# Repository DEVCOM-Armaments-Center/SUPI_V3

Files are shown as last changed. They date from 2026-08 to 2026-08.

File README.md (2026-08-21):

# sUPI — Small Universal Payload Interface

**Technical Data Package, Version 3.3**

> **DISTRIBUTION STATEMENT A. APPROVED FOR PUBLIC RELEASE; DISTRIBUTION IS UNLIMITED.**

---

## Overview

sUPI is an interchangeable mechanical and electrical interface for attaching payloads to uncrewed
systems, primarily small UAS.

The interface is two mating halves, each with its own machined hardware and circuit board:

| Half | Mounts to | Board | Role |
| --- | --- | --- | --- |
| **Platform Side** | The vehicle | `100069026-001` | Gates and monitors payload power; switches USB; hosts the interface MCU |
| **Payload Side** | The payload | `100068610-001` | Regulates platform battery down to payload rails; carries the payload ID device |

Power, USB, and GPIO cross the interface on spring contacts, so the halves mate and separate without
a cable or locking connector. The platform side is the intelligent end: a detect mechanism lets it
identify an attached payload and gate the payload signals accordingly.

Start with [`sUPI_Platform_Brief.md`](sUPI_Platform_Brief.md) or
[`sUPI_Payload_Brief.md`](sUPI_Payload_Brief.md) depending on which side you are integrating.

---

## Electrical Interface

### Platform → Platform-Side Board

| Signal | Range |
| --- | --- |
| `VBATT` / `VBATT_RET` | 13 – 25.2 VDC (4S–6S pack) |
| `GPIO` | Typically PWM, ±5 VDC |
| `USB` | 0 – 3.3 VDC |

### Payload-Side Board → Payload

| Signal | Range |
| --- | --- |
| `VBATT` / `VBATT_RET` | 13 – 25.2 VDC, passed through |
| `V1` | Regulated **3.3 or 5 VDC** — set by solder bridge |
| `V2` | Regulated **5, 7.4, or 12 VDC** — set by solder bridge |
| `GPIO` | Typically PWM, ±5 VDC |
| `USB` | 0 – 3.3 VDC |

> **V1 and V2 are hardware-selected.** The rails are set by solder-bridge placement
> at build time. Verify the bridges match the payload before first power-on.

Both boards use solder pads for field wiring: 18–22 AWG for power, 24–30 AWG for signals.

### Board Markings

- **Platform pads:** `VBATT`, `GND`, `GPIO 0`, `GPIO 1`, `+USB−`, `AUX`
- **Platform jumpers:** `DETECT PAYLOAD`, `SELECT`, `FORCE ON`, `LO BATT CUTOFF`
- **Payload pads:** `VBATT`, `GND`, `V1`, `V1 OK`, `V2`, `V2 OK`, `USB DP`, `USB DM`, `GPIO 0`, `GPIO 1`
- **Payload selectors:** `V1SEL` (`3V3` / `5V`), `V2SEL` (`5V` / `7V4` / `12V`)

`FORCE ON` overrides the detect gate — confirm its state before flight.

### Functional Blocks

**Platform side** — 8-layer board.

| Function | Device |
| --- | --- |
| Interface MCU | STM32C011F6 (Arm Cortex-M0+) |
| Payload power switch | MPQ5069, 15 A |
| Current sense | ACS711, ±15 A bidirectional Hall-effect |
| Ideal-diode / reverse-polarity control | NCV68261 driving an N-channel MOSFET |
| Undervoltage supervisor | LTC2965 |
| Logic 3.3 V rail | NCP730 LDO, 150 mA |
| USB routing | TC7USB40MU dual SPDT, MAX20336 DPST |
| Transient protection | 26 V bidirectional TVS on `VBATT`, 3.3 V TVS on signals |

**Payload side** — 4-layer board.

| Function | Device |
| --- | --- |
| V1 / V2 regulation | MAX25254, dual 36 V in / 0.8–14 V out, 8 A synchronous buck |
| Payload ID / detect | DS2431 1-Wire EEPROM, 1 kbit |
| Input protection | NCV68261 + N-channel MOSFET, P-channel blocking FET |
| Logic 3.3 V rail | NCP730 LDO, 150 mA |
| Supply supervisor | MAX821, 2.78 V |
| USB routing | TC7USB40MU dual SPDT, MAX20336 DPST |
| Transient protection | 26 V unidirectional TVS on `VBATT`, 3.3 V TVS on signals |

The DS2431 is what the platform MCU reads to identify an attached payload — a payload built to this
interface inherits an identity device it does not have to implement itself.

### Mating Connection

A **9-contact, 0.100"-pitch right-angle spring-pin interface.** The payload side carries the spring
pins (Mill-Max 829-series); the platform side carries the mating targets (Mill-Max 399-series).

---

## Mechanical Interface

Both halves mount with **M3 × 0.5 mm thread, 8 mm long, black-oxide stainless steel Phillips
flat-head screws.**

| Half | Screws | Controlling drawing |
| --- | --- | --- |
| Platform side | 3X M3 | `19200_13122518` |
| Payload side | 4X M3 | `19200_13122514` |

Two accepted installation methods, either half:

1. **Direct mount** — drill and tap the sUPI hole pattern into the host structure.
2. **Adapter** — fabricate an adapter carrying the sUPI hole pattern on one face and mating to an
   existing interface on the other. Preferred where the host structure cannot be modified.

The payload-side pattern carries a `VEHICLE CG` reference callout — position the interface so the
vehicle center of gravity lands as close to that point as the installation allows.

### Part Tree

Assembly **13122513**, one each of:

| Part No. | Nomenclature | Material | Process / Finish |
| --- | --- | --- | --- |
| `13122514` | V-Mount Base | 6061-T6 per ASTM B209, or polymer powder bed fusion | Bead blast; hard anodize per MIL-A-8625F Type III Class 2, black, sealed |
| `13122515` | Short Button | 6061-T6 per ASTM B209 | Bead blast; hard anodize per MIL-A-8625F Type III Class 2, black, sealed |
| `13122516` | Small Button Cover | PA12 or PA6 | Polymer powder bed fusion (MJF, SLS, or SAF); depowder, media blast, optional black dye |
| `13122517` | Connector Cover | 6061-T6 per ASTM B209, or polymer powder bed fusion | Bead blast; hard anodize per MIL-A-8625F Type III Class 2, black, sealed |
| `13122518` | V-Mount | 6061-T6 per ASTM B209 | Mask/plug threaded holes, then bead blast and hard anodize per MIL-A-8625F Type III Class 2, black, sealed |

Threaded and clearance features:

- `13122514` — 4× M3 clearance, 90° countersunk; 2× M2 × 0.4 tapped
- `13122517` — 2× M2 × 0.4 clearance
- `13122518` — 3× M3 clearance, 90° countersunk; 3× M1.6 × 0.35 tapped, through

Dimensions are in inches; interpret per ANSI/ASME Y14.5M-2009. **The drawings are the authority** —
each detail sheet names a design model required to complete the product definition, and
undimensioned features are taken from that model. Do not machine from the PDFs alone.

---

## Before You Fabricate Boards

The three notes in `sUPI Electrical/` supersede the released BOMs. Read them first.

| Note | Direction |
| --- | --- |
| [`MFR_DNP.md`](sUPI%20Electrical/MFR_DNP.md) | Do not populate platform `U3`, `R1`–`R4`, `C2`, `JP1` — the undervoltage cutoff is still in development and can block power to the payload |
| [`MFR_Rework.md`](sUPI%20Electrical/MFR_Rework.md) | Remove platform `U11` and `U12` and bridge pin 2 to pin 4 on each footprint — a bare do-not-populate leaves the net open and does not implement the workaround |
| [`MFR_Capacitors.md`](sUPI%20Electrical/MFR_Capacitors.md) | Alternate capacitor part numbers for every Murata position on both boards |

With the do-not-populate and rework direction applied, the platform board has **no undervoltage
supervision and no supply supervisor**, and its detect/enable gate is strapped to a permanent
pass-through. If your application depends on brownout protection or supervised power sequencing,
treat that as an open engineering item.

---

## Firmware

`supi_firmware.hex` is the platform MCU image: 20,440 bytes, load address `0x08000000`, targeting the
STM32C011 (Arm Cortex-M0+). Intel HEX format.

---

## Revision History

See [`CHANGELOG.md`](CHANGELOG.md).

v3.3 is a manufacturability and fit release — it removes special tooling from the machining plan and
takes slop out of the mating stack. No electrical interface changes.

**v3.3 hardware is physically marked.** Check the engraved version number before mating
mixed-vintage halves: earlier parts have looser fit, and earlier `13122515` buttons have the taller
profile that was prone to bending.

---

## Package Contents

```
.
├── CHANGELOG.md                     Design change history, v3.1 → v3.3
├── sUPI_Platform_Brief.md           Platform-side integration brief
├── sUPI_Payload_Brief.md            Payload-side integration brief
├── assets/                          Figures for the briefs and changelog
│
├── sUPI Mechanicals/
│   ├── 19200_13122513_v3-3.pdf      Assembly drawing
│   ├── 19200_1312251[4-8]_v3-3.pdf  Detail drawings
│   └── 19200_*_v3-3.stp             Solid models (STEP)
│
├── sUPI Electrical/
│   ├── MFR_DNP.md                   Do-not-populate direction
│   ├── MFR_Rework.md                Platform rework work instructions
│   ├── MFR_Capacitors.md            Capacitor alternate sourcing
│   ├── Platform/
│   │   ├── 100046138_Rev2.pdf       Schematic
│   │   ├── 100069026-001_Rev1_FAB_DWG.pdf
│   │   ├── *.gbr                    Gerbers — 8 copper layers
│   │   ├── *.drl, *-DRL.rpt         Drill files and report
│   │   ├── *.d356                   Bare-board test netlist
│   │   └── *_Rev2__platform_VAL_bom.xlsx
│   └── Payload/
│       ├── 100046137_Rev2.pdf       Schematic
│       ├── 100068610-001_Rev1_FAB_DWG.pdf
│       ├── *.gbr                    Gerbers — 4 copper layers
│       ├── *.drl, *-DRL.rpt         Drill files and report
│       ├── *.d356                   Bare-board test netlist
│       └── *_Rev2_payload_VAL_bom.xlsx
│
└── sUPI Firmware/
    └── supi_firmware.hex            Platform MCU image
```

### Where to Start

| You are | Read, in order |
| --- | --- |
| **Platform integrator** | Platform brief → assembly drawing → platform schematic |
| **Payload integrator** | Payload brief → assembly drawing → payload schematic |
| **Fabricating boards** | `MFR_*.md` notes → BOM → Gerbers, drill, fab drawing |
| **Machining parts** | Detail drawing + its matching STEP model |
| **Bringing up firmware** | Platform schematic, MCU section → `supi_firmware.hex` |

---

## Conventions

- **Mechanical part numbers** are 8-digit design-activity numbers, prefixed in filenames with CAGE
  code `19200` and suffixed with the TDP version (`_v3-3`).
- **Electrical part numbers** are 9-digit with a `-001` dash number and an explicit `_Rev`.
- **Dimensions** are in inches unless otherwise specified; tolerances per ANSI/ASME Y14.5M-2009.
  Untoleranced features carry a 0.005 profile tolerance to datums A-B-C.
- **Mechanical files:** `.pdf` released drawing, `.stp` neutral solid model.
- **Electrical files:** `.pdf` schematic and fab drawing, `.gbr` Gerber layer, `.drl` drill, `.d356`
  bare-board test netlist, `.xlsx` BOM.
- **Packaging and marking** per MIL-STD-2073-1 Method 10 and MIL-STD-130.

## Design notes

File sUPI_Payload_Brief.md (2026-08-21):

# Small Universal Payload Interface (sUPI) — Payload Side Brief

**sUPI v3.3**

> **DISTRIBUTION STATEMENT A. APPROVED FOR PUBLIC RELEASE; DISTRIBUTION IS UNLIMITED.**

---

## Overview

The sUPI interface provides an interchangeable interface to connect payloads to UxS platforms such
as drones. The interface is a subset of the Picatinny Common Lethality Interface Kit (CLIK) Design
Standard. The interface supports a detect mechanism in which the payload signals are controlled by
the platform's interface board. The payload interface board provides power to the payload and
connectivity for USB and GPIOs passed through the physical / electrical interface.

---

## Electrical Interface for Payload

The sUPI payload side electronics board has solder pads for connecting wires to the payload
interfaces. Connections should be made with 18–22 AWG wire for power (`VBATT`, `VBATT_RET`) and
24–30 AWG for signals, as indicated in the wiring diagram (Figure 1).

The payload board will provide regulated power based upon solder bridge placement over the `V1SEL`
and `V2SEL` selections.

| Signal | Range |
| --- | --- |
| `VBATT` | Platform battery, 13 to 25.2 VDC |
| `VBATT_RET` | Battery return |
| `V1` | Regulated power, 3.3 or 5 VDC |
| `V2` | Regulated power, 5, 7.4 or 12 VDC |
| `GPIO` | Typically PWM, ±5 VDC |
| `USB` | 0 to 3.3 VDC |

### Rail Selection

`V1` and `V2` are set by solder bridge at build time; there is no runtime negotiation. Verify the
bridges match the payload's requirements before first power-on.

| Selector | Options |
| --- | --- |
| `V1SEL` | `3V3` or `5V` |
| `V2SEL` | `5V`, `7V4` (7.4 V), or `12V` |

### Solder Pads

The payload board silkscreen labels its wiring pads directly: `VBATT`, `GND`, `V1`, `V1 OK`, `V2`,
`V2 OK`, `USB DP`, `USB DM`, `GPIO 0`, `GPIO 1`.

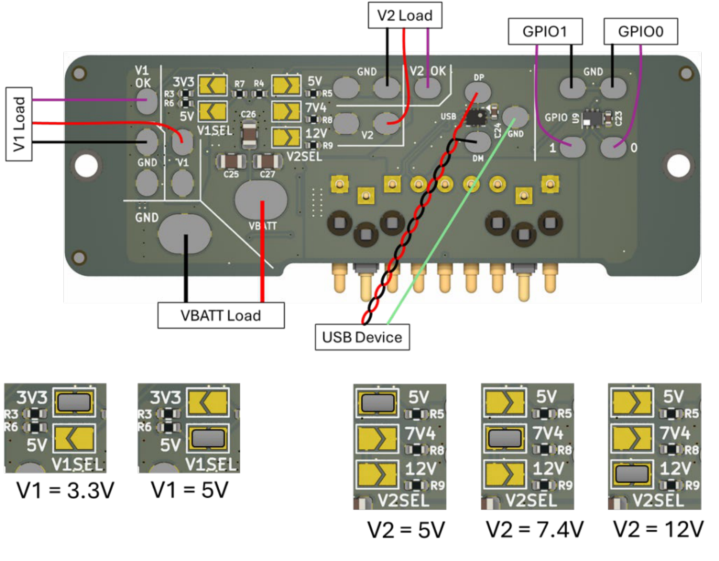
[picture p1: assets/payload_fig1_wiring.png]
Figure 1 — Payload side wiring and rail selection. Board pads at top; V1SEL and V2SEL solder bridge options below.


**Figure 1.** Payload side wiring diagram and rail selection. Lower panels show the valid `V1SEL`
and `V2SEL` solder bridge placements.

---

## Mechanical Interface for Payload

The sUPI Payload Side is intended to be mounted to a payload via **4X M3 × 0.5 mm thread, 8 mm
long, black-oxide stainless steel Phillips flat head screws** (e.g. McMaster PN 91698A304). The
mounting hole pattern is shown in Figure 2.

Existing payloads should be modified in one of the following ways to install a sUPI Payload Side
interface:

- **Drill and tap 4X holes** into the payload as shown in Figure 2, in the desired location for
  mounting the sUPI payload side. For a UAV platform, it is recommended that the vehicle CG align as
  closely as possible with the point indicated in Figure 2.
- **Create a custom adapter** that includes the sUPI Payload Side hole pattern and enables mounting
  to an existing mounting interface on a payload.

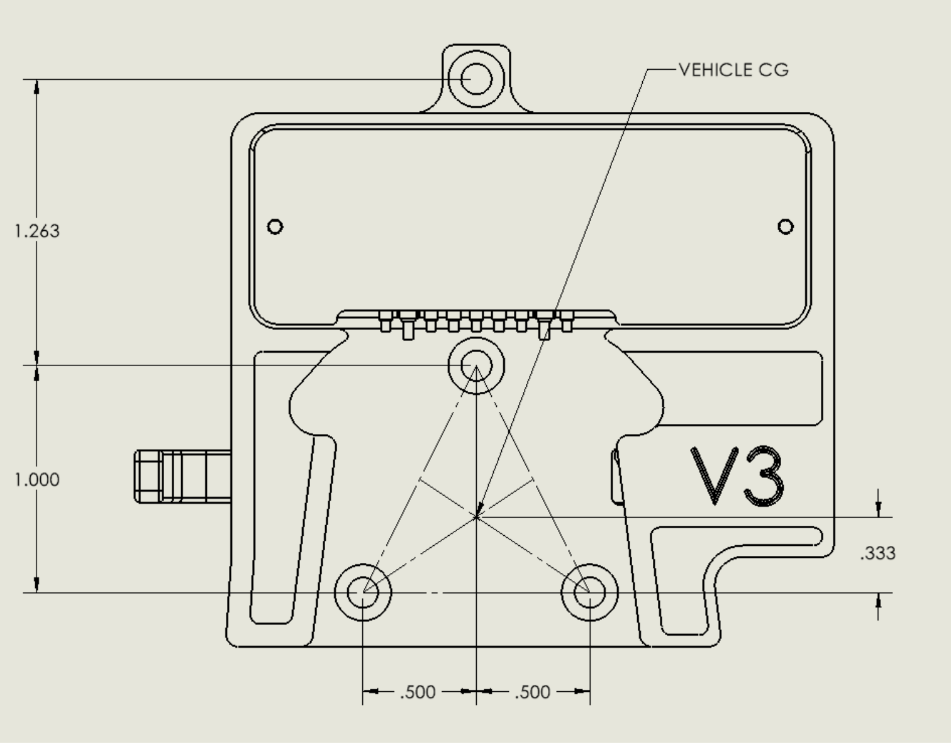
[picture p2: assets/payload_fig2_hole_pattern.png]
Figure 2 — Payload side mounting hole pattern, four M3 holes, with the vehicle CG reference point marked


**Figure 2.** Payload side mounting hole pattern — 4X M3, viewed from the mounting face. Dimensions
in inches. The `VEHICLE CG` callout marks the recommended center-of-gravity reference point. The two
smaller holes are M2 board-mounting features, not host mounting points.

Refer to drawing `19200_13122514` for controlling dimensions and tolerances.

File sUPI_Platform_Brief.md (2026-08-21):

# Small Universal Payload Interface (sUPI) — Platform Side Brief

**sUPI v3.3**

> **DISTRIBUTION STATEMENT A. APPROVED FOR PUBLIC RELEASE; DISTRIBUTION IS UNLIMITED.**

---

## Overview

The sUPI interface provides an interchangeable interface to connect payloads to UxS platforms such
as drones. The interface is a subset of the Picatinny Common Lethality Interface Kit (CLIK) Design
Standard. The interface supports a detect mechanism in which the payload signals are controlled by
the platform's interface board. The payload interface board provides power to the payload and
connectivity for USB and GPIOs passed through the physical / electrical interface.

---

## Electrical Interface for Platform

The sUPI platform side electronics board has solder pads for connecting wires to platform avionics.
Connections should be made with 18–22 AWG wire for power (`VBATT`, `VBATT_RET`) and 24–30 AWG for
signals, as indicated in the wiring diagram (Figure 1).

The platform will need to provide the following to the sUPI interface board:

| Signal | Range |
| --- | --- |
| `VBATT` | Platform battery, 13 to 25.2 VDC |
| `VBATT_RET` | Battery return |
| `GPIO` | Typically PWM, ±5 VDC |
| `USB` | 0 to 3.3 VDC |

The 13 to 25.2 VDC range corresponds to a 4S–6S lithium-polymer pack.

### Solder Pads and Jumpers

The platform board silkscreen labels its wiring pads and configuration jumpers directly:

- **Wiring pads:** `VBATT`, `GND`, `GPIO 0`, `GPIO 1`, `+USB−`, `AUX`
- **Configuration jumpers:** `DETECT PAYLOAD`, `SELECT`, `FORCE ON`, `LO BATT CUTOFF`

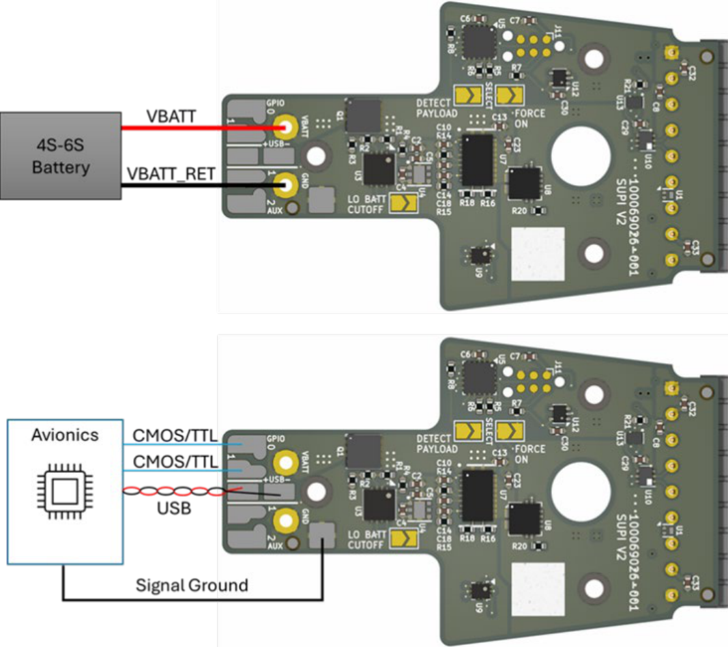
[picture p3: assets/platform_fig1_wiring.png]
Figure 1 — Platform side wiring. Top: battery connection to VBATT and GND. Bottom: avionics connections to GPIO, USB, and ground.


**Figure 1.** Platform side wiring diagram. Battery to `VBATT` / `GND`; avionics to `GPIO`, `+USB−`,
and ground.

---

## Mechanical Interface for Platform

The sUPI Platform Side is intended to be mounted to a platform via **3X M3 × 0.5 mm thread, 8 mm
long, black-oxide stainless steel Phillips flat head screws** (e.g. McMaster PN 91698A304). The
mounting hole pattern is shown in Figure 2.

Platforms should be modified in one of the following ways to install a sUPI Platform Side
interface:

- **Drill and tap 3X holes** into the platform as shown in Figure 2, in the desired location for
  mounting the sUPI Platform Side.
- **Create a custom adapter** that includes the sUPI platform side hole pattern and enables mounting
  to an existing mounting interface on a platform.

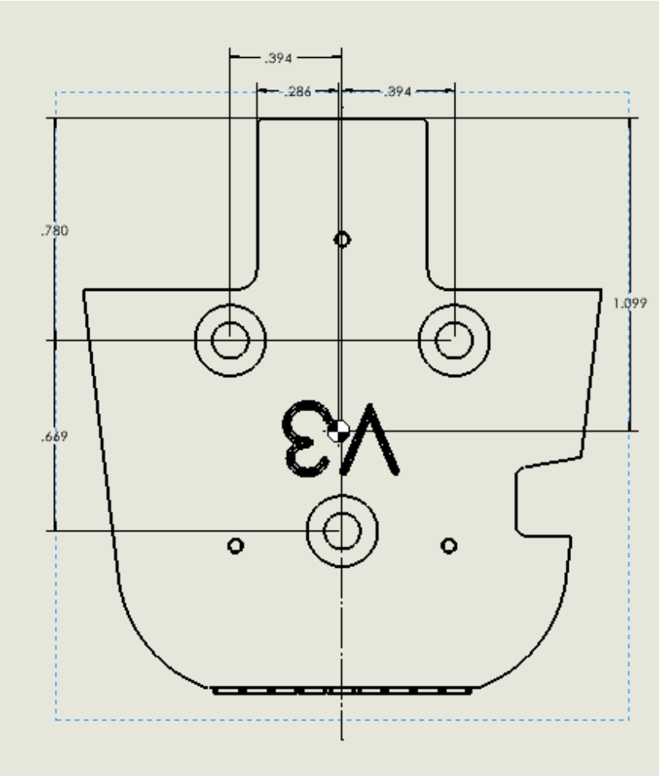
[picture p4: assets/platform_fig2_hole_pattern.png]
Figure 2 — Platform side mounting hole pattern, three M3 holes


**Figure 2.** Platform side mounting hole pattern — 3X M3, viewed from the mounting face.
Dimensions in inches. The three smaller holes are M1.6 board-mounting features, not host mounting
points.

Refer to drawing `19200_13122518` for controlling dimensions and tolerances.

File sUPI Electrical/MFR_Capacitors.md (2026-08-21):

# sUPI Electrical Interfaces — Capacitors

**DEPARTMENT OF THE ARMY**
U.S. Army Combat Capabilities Development Command, Armaments Center
Picatinny Arsenal, New Jersey 07806-5000

| | |
| --- | --- |
| **Office Symbol** | FCDD-ACE-P |
| **Date** | 30 March 2026 |
| **Subject** | sUPI Electrical Interfaces Capacitors |
| **Applies to** | Payload board `100068610-001`, platform board `100069026-001` |

> **DISTRIBUTION STATEMENT A. APPROVED FOR PUBLIC RELEASE; DISTRIBUTION IS UNLIMITED.**

---

## Background

Note Murata's business statement regarding the use of their products for weapon systems:
<https://www.murata.com/en-us/support/militaryrestriction>

To reduce burden, the following have been identified as possible alternatives. Values, dielectrics,
voltage ratings, and package sizes are unchanged from the released BOMs.

---

## Payload — `100068610-001`

| Ref | Qty | Value | Description | Alternate MPN | Manufacturer |
| --- | --- | --- | --- | --- | --- |
| `C1`, `C6` | 2 | 4.7 µF 50 V | CAP CER 4.7UF 50V X7R 0805 | `C2012X7R1H475K125AC` | TDK |
| `C2` | 1 | 2.2 µF 35 V | CAP CER 2.2UF 35V X5R 0402 | `C1005X5R1V225K050BC` | TDK |
| `C3` | 1 | 10 µF 50 V | CAP CER 10UF 50V X5R 0805 | `CL21A106KBYQNNE` | Samsung |
| `C4`, `C7`, `C10`, `C11`, `C21`, `C22`, `C23`, `C24` | 8 | 0.1 µF 50 V | CAP CER 0.1UF 50V X7R 0402 | `CGA2B3X7R1H104M050BB` | TDK |
| `C5`, `C9` | 2 | 10 µF 6.3 V | CAP CER 10UF 6.3V X5R 0402 | `GMC04X5R106M6R3NT` | CAL-Chip Electronics |
| `C8` | 1 | 10000 pF 50 V | CAP CER 10000PF 50V X7R 0402 | `CGA2B3X7R1H103K050BB` | TDK |
| `C12`, `C13` | 2 | 10 pF 50 V | CAP CER 10PF 50V C0G/NP0 0402 | `04025U100F4T2A` | Kyocera AVX |
| `C14`, `C15`, `C16`, `C17`, `C18`, `C19` | 6 | 22 µF 25 V | CAP CER 22UF 25V X5R 0805 | `C2012X5R1V226M125AC` | TDK |

## Platform — `100069026-001`

| Ref | Qty | Value | Description | Alternate MPN | Manufacturer |
| --- | --- | --- | --- | --- | --- |
| `C1`, `C2`, `C6`, `C7`, `C13`, `C18`, `C23`, `C27`, `C28`, `C29`, `C30`, `C31`, `C32`, `C33` | 14 | 0.1 µF 50 V | CAP CER 0.1UF 50V X7R 0402 | `C1005X7R1H104K050BB` | TDK |
| `C3`, `C11`, `C12` | 3 | 10 µF 50 V | CAP CER 10UF 50V X5R 0805 | `C0805B106K050T` | Holy Stone Enterprise Co |
| `C4`, `C14` | 2 | 10000 pF 50 V | CAP CER 10000PF 50V X7R 0402 | `CC0402KRX7R9BB103` | YAGEO |
| `C5`, `C9` | 2 | 10 µF 6.3 V | CAP CER 10UF 6.3V X5R 0402 | `CL05A106MP5NUNC` | Samsung |
| `C8` | 1 | 4700 pF 50 V | CAP CER 4700PF 50V X7R 0402 | `C0402C472K5RACTU` | Kemet |
| `C10` | 1 | 0.33 µF 10 V | CAP CER 0.33UF 10V X5R 0402 | `CGA2B1X7S1C334M050BC` | TDK |
| `C24` | 1 | 4.7 µF 50 V | CAP CER 4.7UF 50V X7R 0805 | `CGA4J1X7R1H475K125AC` | TDK |

---

## Positions Not Covered

These BOM positions are **not** Murata parts as released and need no substitution:

- Payload `C25`, `C26`, `C27` — 22 µF 35 V, `C2012X5R1V226M125AC`, TDK
- Platform `C15`, `C16`, `C17`, `C19`, `C20`, `C21`, `C22` — 22 µF 35 V, `C2012X5R1V226M125AC`, TDK

Every other capacitor position on both boards is Murata as released and is addressed above. Note
that the released **platform** `C10` is a `GRT`-series part (automotive, soft-termination); the
alternate is an `X7S` dielectric rather than the original `X5R`. Confirm this is acceptable for the
application's temperature range.

---

**Respectfully submitted,**

Robert Barone Jr, PMP\
Special Project APO\
U.S. Army Combat Capabilities Development Command, Armaments Center\
Picatinny Arsenal, NJ 07806\
W: 520-684-1640

---

*Converted from `MFR_Capacitors.pdf`. Tables are verbatim from the source memo. The "Positions Not
Covered" section was added by cross-checking the source against the released BOMs
(`100068610-001_Rev2`, `100069026-001_Rev2`).*

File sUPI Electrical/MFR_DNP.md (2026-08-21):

# sUPI Electrical Interfaces — Do Not Populate

**DEPARTMENT OF THE ARMY**
U.S. Army Combat Capabilities Development Command, Armaments Center
Picatinny Arsenal, New Jersey 07806-5000

| | |
| --- | --- |
| **Office Symbol** | FCDD-ACE-P |
| **Date** | 30 March 2026 |
| **Subject** | sUPI Electrical Interfaces Do Not Populate |
| **Applies to** | Platform board `100069026-001` |

> **DISTRIBUTION STATEMENT A. APPROVED FOR PUBLIC RELEASE; DISTRIBUTION IS UNLIMITED.**

---

## Direction

The low-battery / undervoltage cutoff feature of the sUPI reference design is under development and
in its current form can prevent power being supplied to sUPI payloads.

Unless the feature is specifically required, **do not populate** the following components on the
**platform** board. Omitting them is also a cost saving.

| Reference | Device | Function |
| --- | --- | --- |
| `U3` | LTC2965HDD | Undervoltage supervisor |
| `R1` | 787 kΩ, 1%, 0402 | Undervoltage threshold divider |
| `R2` | 12.4 kΩ, 0.1%, 0402 | Undervoltage threshold divider |
| `R3` | 200 kΩ, 0.1%, 0402 | Undervoltage threshold divider |
| `R4` | 1 kΩ, 1%, 0402 | Supervisor support |
| `C2` | 0.1 µF, 50 V, 0402 | Supervisor decoupling |
| `JP1` | — | Low-battery cutoff jumper |

**Effect:** the platform board is built without undervoltage lockout. Payload power will not be
inhibited on a falling battery. If your application depends on brownout protection, implement it
upstream in platform avionics or treat it as an open engineering item.

---

**Respectfully submitted,**

Robert Barone Jr, PMP\
Special Project APO\
U.S. Army Combat Capabilities Development Command, Armaments Center\
Picatinny Arsenal, NJ 07806\
W: 520-684-1640

---

*Converted from `MFR_DNP.pdf`. Component values and functions in the table above were added from
the platform BOM (`100069026-001_Rev2`) and schematic (`100046138_Rev2`) for readability; the
reference designator list is verbatim from the source memo.*

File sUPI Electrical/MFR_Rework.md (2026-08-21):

# sUPI Electrical Interfaces — Platform Rework

**DEPARTMENT OF THE ARMY**
U.S. Army Combat Capabilities Development Command, Armaments Center
Picatinny Arsenal, New Jersey 07806-5000

| | |
| --- | --- |
| **Office Symbol** | FCDD-ACE-P |
| **Date** | 30 March 2026 |
| **Subject** | sUPI Electrical Interfaces Platform Rework |
| **Applies to** | Platform board `100069026-001` |

> **DISTRIBUTION STATEMENT A. APPROVED FOR PUBLIC RELEASE; DISTRIBUTION IS UNLIMITED.**

---

## Problem

During platform testing, current draw and voltage drops during certain high-demand maneuvers
resulted in intermittent issues with some of the logic gates on the platform board.

## Direction

The short-term workaround is to remove `U12` and `U11` from the platform board **and bridge across
each footprint**, so the removed device is bypassed rather than left open.

> **Note:** the memo body describes this as "do not populate," but the work instructions below
> require a jumper wire in both positions. A bare DNP leaves the net floating and does **not**
> implement this workaround. Follow the work instructions.

| Reference | Device | Function | Action |
| --- | --- | --- | --- |
| `U12` | SN74LVC1G08DRLR | Single AND gate, low-voltage CMOS | Remove; wire pin 2 to pin 4 |
| `U11` | MAX821UUS+T | Supply supervisor, 2.78 V, SOT143-4 | Remove; wire pin 2 to pin 4, no connection to pin 1 or 3 |

---

### `U12` Rework

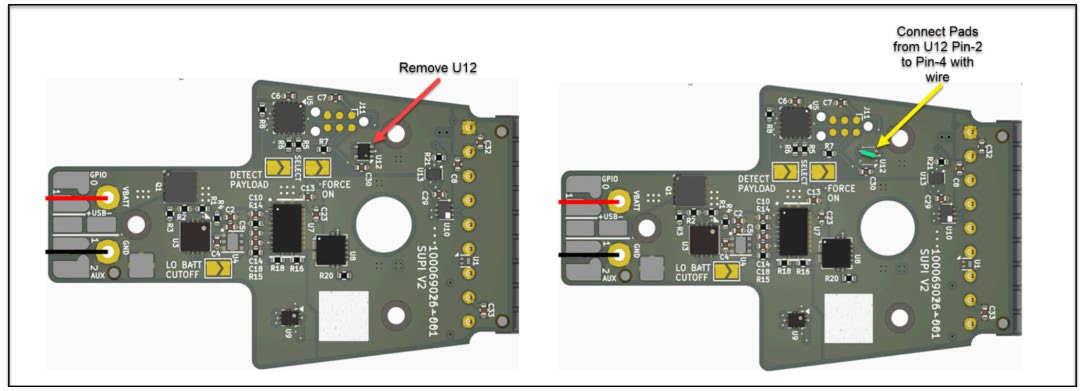
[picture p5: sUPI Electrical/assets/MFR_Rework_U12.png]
U12 rework — remove U12, then connect pads from U12 pin 2 to pin 4 with wire


1. Remove `U12`.
2. Connect the pads from `U12` pin 2 to pin 4 with wire.

### `U11` Rework

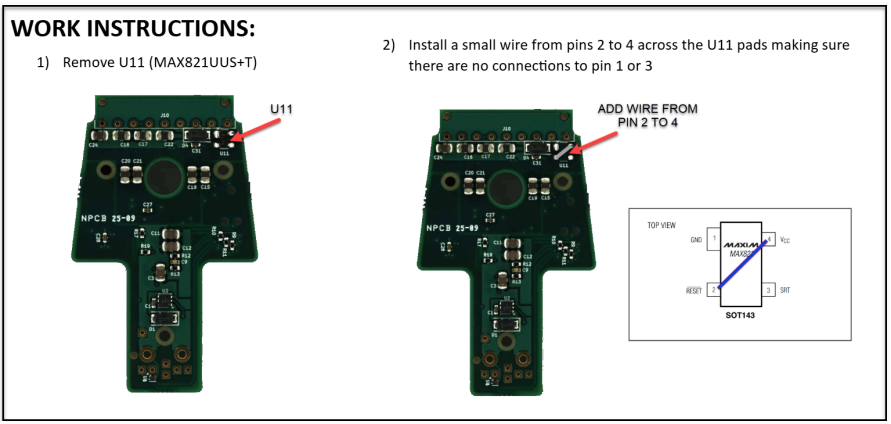
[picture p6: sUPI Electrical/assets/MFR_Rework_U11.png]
U11 work instructions — remove U11, then install a wire from pin 2 to pin 4 across the U11 pads


1. Remove `U11` (MAX821UUS+T).
2. Install a small wire from pins 2 to 4 across the `U11` pads, making sure there are no
   connections to pin 1 or pin 3.

---

## Combined Effect

Applied together with the do-not-populate direction, the platform board ships without **both** its
undervoltage supervisor (`U3`) and its supply supervisor (`U11`), and with its detect/enable AND
gate (`U12`) bypassed to a permanent pass-through. Integrators should not assume the reference
design provides brownout protection or supervised power sequencing.

---

**Respectfully submitted,**

Robert Barone Jr, PMP\
Special Project APO\
U.S. Army Combat Capabilities Development Command, Armaments Center\
Picatinny Arsenal, NJ 07806\
W: 520-684-1640

---

*Converted from `MFR_Rework.pdf`; figures extracted from the source document. Device part numbers
and functions were added from the platform BOM (`100069026-001_Rev2`) for readability. Note that the
photographed boards are silkscreened `SUPI V2` — verify designator locations against the v3.3
fabrication drawing before reworking current hardware.*

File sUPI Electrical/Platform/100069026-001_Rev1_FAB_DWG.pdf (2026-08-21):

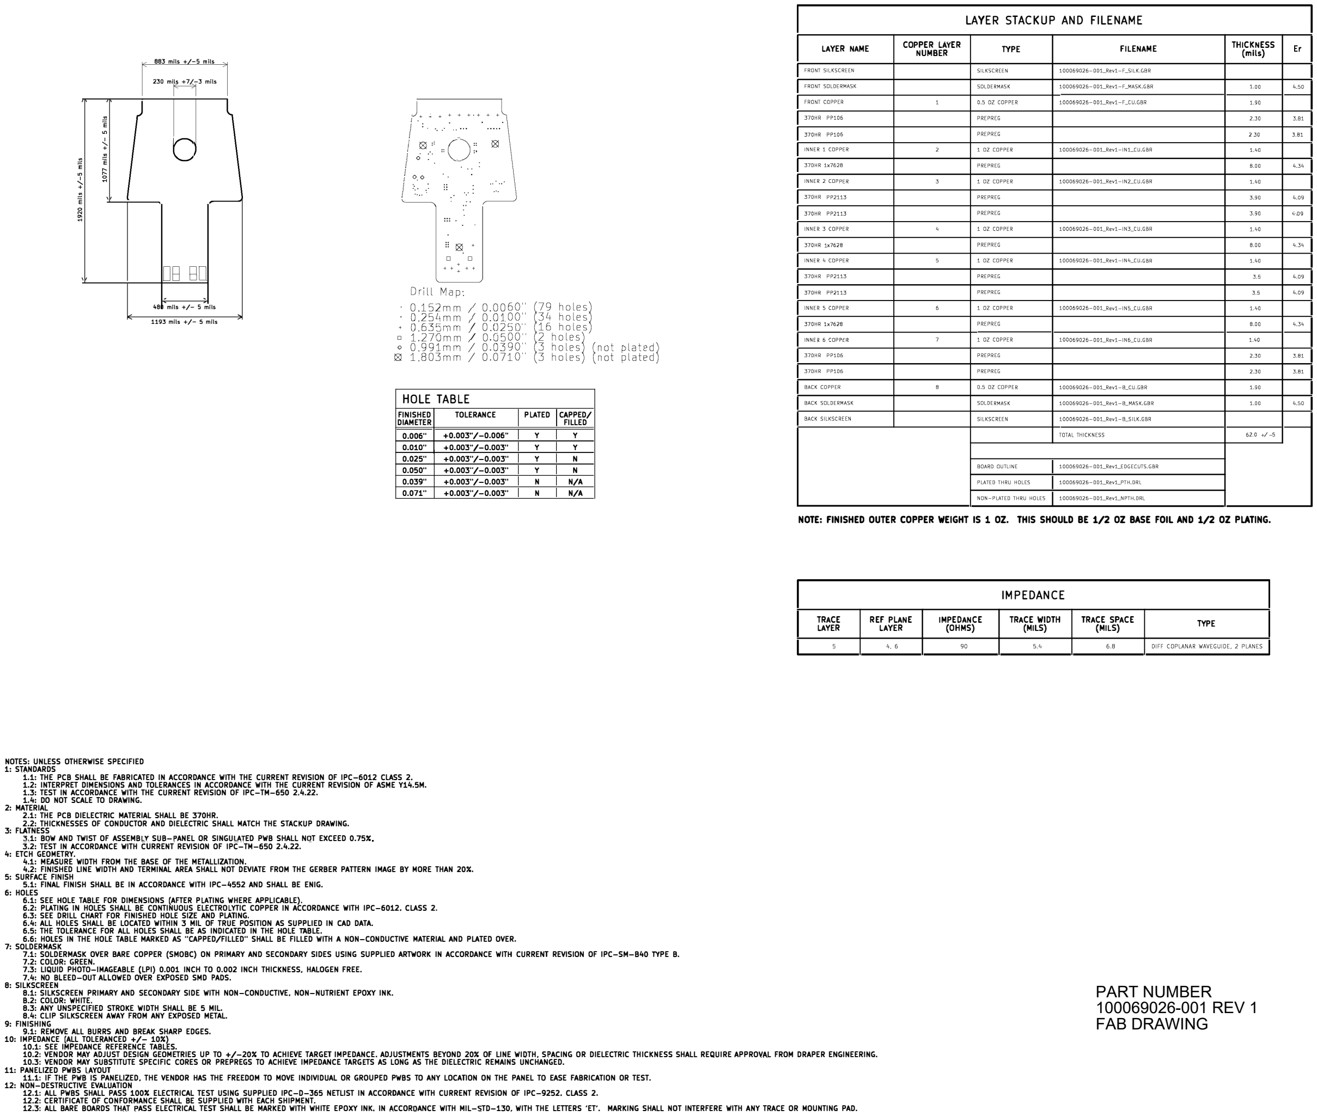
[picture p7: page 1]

663 mils +/-5 mils

)
C

lR =-
480 mil, ½/- 5 mils
1193 mil, +/- 5 mil,

,J' - '
I
I
,I 0:
I o
I
I

/-⁻,,:: I\,_):·
I ◊, ◊
I
I
·
| -)rill fl,1r,· Ci '._<.,'.nn / C.:J:J J )'l"-nn 'c.:)1
+ ::, tl.)'·1··11·1 / C :1J'J :·" 7 1.7:;nn / C :J:.i
<> D 991 r·w1 / C :n
01 1 G03n1 / C :)7::_

HOLE TABLE
FINISHED TOLERANCE PLATED
DIAMETER 0.006" | FILLED +0.003"/-0.006" y
| y
0.025" 0.010" | +0.003"/-0.003" y N +0.003"/-0.003" y y
0.050" | +0.003"/-0.003" y N
0.071" | +0.003"/-0.003" N N/A
0.039" | +0.003"/-0.003" N

CAPPED/

N/A

(rrnl ·l.i-ll-_,d\
,,not ::1.atd::

LAYER NAME

37CIIP FPi:6

37CHR FP2C13
'i7GIIP ,7c7!
37CIIR rP2'.13
37CHR c,7l28
INNC' b '.Cl'l'cl!

COPPER LAYER
NUMBER

LAYER STACKUP AND FILENAME
NPE | FILENAME

THICKNESS
(mils)

2 30

,.s
1\W

62' I '.

NOTE: FINISHED OUTER COPPER WEIGHT IS 1 OZ. THIS SHOULD BE 1/2 OZ BASE FOIL AND 1/2 OZ PLATING.

NOTES: UNLESS OTHERWISE SPECIFIED
1: STANDARDS
1.1: THE PCB SHALL BE FABRICATED IN ACCORDANCE WITH THE CURRENT REVISION OF IPC-6012 Cl.ASS 2, 1.2: INTERPRET DIMENSIONS AND TOLERANCES IN ACCOROANCE WITH THE CURRENT REVISION OF ASME Y14.5M. 1.3: TEST IN ACCORDANCE WITH THE CURRENT REVISION OF IPC-TM-650 2.4.22.
1.4: DO NOT SCALE TO DRAWING.
2: MATERIAL
2.1: THE PCB DIELECTRIC MATERIAL SHALL BE 370HR.
2.2: THICKNESSES OF CONDUCTOR AND DIELECTRIC SHALL MATCH THE STACKUP DRAWING.
3: FLATNESS
:'1.1: BOW AND TWIST OF ASSEMBLY SUB-PANEL OR SINGULATEO PWB SHALL NOT EXCEED 0.75% 3.2: TEST IN ACCORDANCE WITH CURRENT REVISION OF IPC-TM-650 2.4.22.
4: ETCH GEOMETRY.
4.1: MEASURE WIDTH FROM THE BASE OF THE METALLIZATION.
4,2: FINISHED LINE WIDTH ANO TERMINAL AREA SHALL NOT DEVIATE FROM THE GERBER PATTERN IMAGE BY MORE THAN 20X. 5: SURFACE FINISH
5.1: FINAL FINISH SHALL BE IN ACCORDANCE WITH IPC-4552 AND SHALL BE ENIG.
6: HOLES
6.1: SEE HOLE TABLE FOR DIMENSIONS (AFTER PLATING WHERE APPLICABLE).
6.2: PLATING IN HOLES SHALL BE CONTINUOUS ELECTROLYTIC COPPER IN ACCORDANCE WITH IPC-6012, CLASS 2, 6.3: SEE DRILL CHART FDR FINISHED HOLE SIZE ANO PLATING.
6.4: ALL HOLES SHALL BE LOCATED WITHIN 3 MIL OF TRUE POSITION AS SUPPLIED IN CAD DATA.
6.5: THE TOLERANCE FOR ALL HOLES SHALL BE AS INDICATED IN THE HOLE TABLE.
6.6: HOLES IN THE HOLE TABLE MARKED AS "CAPPED/FILLED" SHALL BE FILLED WITH A NON-CONDUCTIVE MATERIAL AND PLATED OVER.
7: S□LDERMASK
7.1: SDLDERMASK OVER BARE COPPER (SMDBC) ON PRIMARY AND SECONDARY SIDES USING SUPPLIED ARTWORK IN ACCORDANCE WITH CURRENT REVISION OF IPC-SM-B40 T'/PE B. 7.2: COLOR: GREEN.
7.3: LIQUID PHOTD-IMAGEABLE {LPI) 0.001 INCH TO 0.002 INCH THICKNESS, HALOGEN FREE.
7.4: ND BLEED-OUT ALLOWED OVER EXPOSED SM□ PADS.
8: SILKSCREEN
8.1: SILKSCREEN PRIMARY ANO SECONDARY SIDE WITH NON-CONDUCTIVE, NON-NUTRIENT EPOXY INK. B.2: COLOR: WHITE.
8.3: ANY UNSPECIFIED STROKE WIDTH SHALL BE 5 MIL.
8.4: CLIP SILKSCREEN AWAY FROM ANY EXPOSED METAL.
9: FINISHING
9.1: REMOVE ALL BURRS ANO BREAK SHARP EDGES. 10: IMPEDANCE (ALL TOLERANCE□ +/- 10X)
10,1; SEE IMPEDANCE REFERENCE TABLES.

TRACE
LAYER

REF PLANE
LAYER

10.2: VENDOR MAY ADJUST DESIGN GEOMETRIES UP TO +/-20X TO ACHIEVE TARGET IMPEDANCE. ADJUSTMENTS BEYOND 20X OF LINE WIDTH, SPACING OR DIELECTRIC THICKNESS SHALL REQUIRE APPROVAL FROM DRAPER ENGINEERING. 10.3: VENDOR MAY SUBSTITUTE SPECIFIC CORES OR PREPREGS TD ACHIEVE IMPEDANCE TARGETS AS LONG AS THE DIELECTRIC REMAINS UNCHANGED.
11: PANELIZED PWBS LAYOUT
11.1: IF THE PWB IS PANELIZED, THE VENDOR HAS THE FREEDOM TO MOVE INDIVIDUAL OR GROUPED PWBS TO ANY LOCATION ON THE PANEL TD EASE FABRICATION OR TEST.
12: NON-DESTRUCTIVE EVALUATION
12.1: ALL PWBS SHALL PASS 100¾ ELECTRICAL TEST USING SUPPLIED IPC-D-65 NETLIST IN ACCORDANCE WITH CURRENT REVISION OF IPC-9252, CLASS 2.
12.2: CERTIFICATE OF CONFORMANCE SHALL BE SUPPLIED WITH EACH SHIPMENT.
12.3: ALL BARE BOARDS THAT PASS ELECTRICAL TEST SHALL BE MARKED WITH WHITE EPOXY INK, IN ACCORDANCE WITH MIL-STD-130, WITH THE LETTERS 'ET'. MARKING SHALL NOT INTERFERE WITH ANY TRACE OR MOUNTING PAD.

IMPEDANCE
(OHMS)

IMPEDANCE
TRACE WIDTH
(MILS)

c.:,

TRACE SPACE
(MILS) TYPE

3ci

•, C9

PART NUMBER
100069026-001 REV 1
FAB DRAWING

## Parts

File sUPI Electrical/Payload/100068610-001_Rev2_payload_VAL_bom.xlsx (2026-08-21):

Ref | Qnty | Value | Description | MPN | Manufacturer | Component name | Footprint
C1,C6 | 2 | 4.7UF 50V | CAP CER 4.7UF 50V X7R 0805 | GRM21BZ71H475KE15L | MURATA ELECTRONICS | 1a_Murata_Capacitors:GRM21BZ71H475KE15L | Capacitor_SMD:C_0805_2012Metric
C2 | 1 | 2.2UF 35V | CAP CER 2.2UF 35V X5R 0402 | GRM155R6YA225KE11D | MURATA ELECTRONICS | 1a_Murata_Capacitors:GRM155R6YA225KE11D | Capacitor_SMD:C_0402_1005Metric
C3 | 1 | 10UF 50V | CAP CER 10UF 50V X5R 0805 | GRM21BR61H106KE43L | MURATA ELECTRONICS | 1a_Murata_Capacitors:GRM21BR61H106KE43L | Capacitor_SMD:C_0805_2012Metric
C4,C7,C10,C11,C21,C22,C23,C24 | 8 | 0.1UF 50V | CAP CER 0.1UF 50V X7R 0402 | GCM155R71H104ME02D | MURATA ELECTRONICS | 1a_Murata_Capacitors:GCM155R71H104ME02D | Capacitor_SMD:C_0402_1005Metric
C5,C9 | 2 | 10UF 6.3V | CAP CER 10UF 6.3V X5R 0402 | GRM155R60J106ME05D | MURATA ELECTRONICS | 1a_Murata_Capacitors:GRM155R60J106ME05D | Capacitor_SMD:C_0402_1005Metric
C8 | 1 | 10000PF 50V | CAP CER 10000PF 50V X7R 0402 | GCM155R71H103KA55D | MURATA ELECTRONICS | 1a_Murata_Capacitors:GCM155R71H103KA55 | Capacitor_SMD:C_0402_1005Metric
C12,C13 | 2 | 10PF 50V | CAP CER 10PF 50V C0G/NP0 0402 | GCM1555C1H100FA16D | MURATA ELECTRONICS | 1a_Murata_Capacitors:GCM1555C1H100FA16D | Capacitor_SMD:C_0402_1005Metric
C14,C15,C16,C17,C18,C19 | 6 | 22UF 25V | CAP CER 22UF 25V X5R 0805 | GRM21BR61E226ME44L | MURATA ELECTRONICS | 1a_Murata_Capacitors:GRM21BR61E226ME44L | Capacitor_SMD:C_0805_2012Metric
C25,C26,C27 | 3 | 22UF 35V | CAP CER 22UF 35V X5R 0805 | C2012X5R1V226M125AC | TDK CORPORATION | 1a_Misc:C2012X5R1V226M125AC | Capacitor_SMD:C_0805_2012Metric
D1 | 1 | 26VWM | TVS SOD123FL 26V 200W UNIDIR | SMF26A | LITTELFUSE | 1a_Littelfuse:SMF26A | 1a_Littelfuse:SOD-123FL
D2 | 1 | 3.3VWM | TVS DIODE 3.3VWM 6.8VC SOD123FL | SMF3.3 | LITTELFUSE | 1a_Littelfuse:SMF3.3 | 1a_Littelfuse:SOD-123FL
L1,L2 | 2 | 0.47UH | 0.47UH SHIELDED INDUCTOR, 15.6A, 4.6MOHM DCR | XEL4030-471MEC | COILCRAFT | 1a_Misc:XEL4030-471MEC | 1a_Misc:XEL4030-3.1mm
L3 | 1 | 27 OHM @2MHZ | FERRITE BEAD 27 OHM 0806 1LN | MDF2016BSS270C | TDK CORPORATION | 1a_Misc:MDF2016BSS270C | 1a_Misc:0806 SMD
P1,P5 | 2 | ~ | POGO PIN HEADER, 1-PIN, 0.1" PITCH, RIGHT-ANGLE, 55 MIL STROKE | 829-22-001-20-001101 | MILL-MAX | 1a_MillMax:829-22-001-20-001101 | 1a_MillMax:829-22-001-20-001101
P2,P4 | 2 | ~ | POGO PIN HEADER, 1-PIN, 0.1" PITCH, RIGHT-ANGLE, 90 MIL STROKE | 829-22-001-20-002101 | MILL-MAX | 1a_MillMax:829-22-001-20-002101 | 1a_MillMax:829-22-001-20-002101
P3 | 1 | ~ | POGO PIN HEADER, 9-PIN, 0.1" PITCH, RIGHT-ANGLE, 55 MIL STROKE | 829-22-005-20-001101 | MILL-MAX | 1a_MillMax:829-22-005-20-001101 | 1a_MillMax:829-22-005-20-001101
Q1 | 1 | NTTFS2D1N04HL | MOSFET N-CH 40V 24A/150A 8PQFN | NTTFS2D1N04HLTWG | ONSEMI | 1a_Misc:NTTFS2D1N04HL | 1a_Misc:WDFN8_3.3_x_3.3_0.65mm_p
Q2 | 1 | ~ | MOSFET BVDSS: 41V 60V SOT23 T&R | DMP610DL-13 | DIODES INCORPORATED | 1a_Misc:DMP610DL | Package_TO_SOT_SMD:SOT-23
R2,R13,R14 | 3 | 100K 1% 0.1W | RES SMD 100K OHM 1% 1/10W 0402 | ERJ-2RKF1003X | PANASONIC ELECTRONIC COMPONENTS | 1a_Panasonic_Resistors:ERJ-2RKF1003X | Resistor_SMD:R_0402_1005Metric
R3 | 1 | 34.4K 0.1% 1/16W | RES 34.4K OHM 0.1% 1/16W 0402 | TNPW040234K4BEED | VISHAY DALE | 1a_Misc:TNPW040234K4BEED | Resistor_SMD:R_0402_1005Metric
R4,R7 | 2 | 11K 1% 0.1W | RES 11K OHM 1% 1/10W 0402 | ERJ-U02F1102X | PANASONIC ELECTRONIC COMPONENTS | 1a_Panasonic_Resistors:ERJ-U02F1102X | Resistor_SMD:R_0402_1005Metric
R5,R6 | 2 | 57.6K 1% 0.1W | RES SMD 57.6K OHM 1% 1/10W 0402 | ERJ-2RKF5762X | PANASONIC ELECTRONIC COMPONENTS | 1a_Panasonic_Resistors:ERJ-2RKF5762X | Resistor_SMD:R_0402_1005Metric
R8 | 1 | 90.9K 1% 0.1W | RES SMD 90.9K OHM 1% 1/10W 0402 | ERJ-2RKF9092X | PANASONIC ELECTRONIC COMPONENTS | 1a_Panasonic_Resistors:ERJ-2RKF9092X | Resistor_SMD:R_0402_1005Metric
R9 | 1 | 154K 1% 0.1W | RES SMD 154K OHM 1% 1/10W 0402 | ERJ-2RKF1543X | PANASONIC ELECTRONIC COMPONENTS | 1a_Panasonic_Resistors:ERJ-2RKF1543X | Resistor_SMD:R_0402_1005Metric
R10,R11 | 2 | 100 1% 0.1W | RES SMD 100 OHM 1% 1/10W 0402 | ERJ-2RKF1000X | PANASONIC ELECTRONIC COMPONENTS | 1a_Panasonic_Resistors:ERJ-2RKF1000X | Resistor_SMD:R_0402_1005Metric
R12 | 1 | 1.00K | RES 1K OHM 1% 1W 2512 AEC-Q200 | RMCF2512FT1K00 | STACKPOLE ELECTRONICS INC. | 1R_Stackpole_2512_2_E96_1P_1.00k_976k:1.00k | 1a_CommonPassives:R_2512_HandSoldering
U1 | 1 | ~ | TVS DIODE 5VWM 3.4VC DFN1006-3 | PESD5V0C2UM | NEXPERIA | 1a_Misc:PESD5V0C2UM | Package_DFN_QFN:Diodes_DFN1006-3
U2 | 1 | ~ | IC REG LINEAR 3.3V 150MA 6WDFN | NCP730BMT330TBG | ONSEMI | 1a_Misc:NCP730BMT330TBG | 1a_Misc:WDFN6_2x2_0.65p_1.72x1.12mm_EP
U3 | 1 | MAX25254AFDE/VY+ | DUAL 36V INPUT, 0.8-14V OUTPUT, 8A SYNCHRONOUS BUCK CONVERTER | MAX25254AFDE/VY+ | ANALOG DEVICES INC./MAXIM INTEGRATED | 1a_Misc:MAX25254AFDE/VY+ | 1a_Misc:F234A5FY+1
U4 | 1 | DS2431Q+ | EEPROM MEMORY IC 1KBIT 1-WIRE® 2 ΜS 6-TDFN (3X3) | DS2431Q+T&R | ANALOG DEVICES INC./MAXIM INTEGRATED | 1a_Misc:DS2431Q+T&R | Package_DFN_QFN:Maxim_TDFN-6-1EP_3x3mm_P0.95mm_EP1.5x2.3mm
U5 | 1 | NCV68261 | POWER SWITCH/DRIVER 1:1 N-CHANNEL 6-WDFNW (2X2) | NCV68261MTWAITBG | ONSEMI | 1a_Misc:NCV68261 | 1a_Misc:WDFNW6_2x2_0.65p_EP
U6 | 1 | ~ | IC SUPERVISOR 1 CHANNEL 2.78V S78OT143-4 | MAX821UUS+T | ANALOG DEVICES INC./MAXIM INTEGRATED | 1a_Misc:MAX821UUS+T | 1a_Misc:SOT-143 Maxim
U7 | 1 | SN74AUP2G04DRYR | IC INVERTER 2CH 2-INP QFN-6 | SN74AUP2G04DRYR | TEXAS INSTRUMENTS | 1a_Misc:SN74AUP2G04DRYR | 1a_Misc:QFN-6_1.4x1mm_P0.5mm TI DRY6
U8 | 1 | ~ | IC USB SWITCH SPDT DUAL 10UQFN | TC7USB40MU | TOSHIBA SEMICONDUCTOR AND STORAGE | 1a_Misc:TC7USB40MU | 1a_Misc:Toshiba UQFN-10_1.4x1.8mm_P0.4mm
U9 | 1 | ~ | IC SWITCH DPSTX1 330MOHM 6WLP | MAX20336AEFT+ | ANALOG DEVICES INC./MAXIM INTEGRATED | 1a_Misc:MAX20336AEFT+ | 1a_Misc:FC2QFN-6

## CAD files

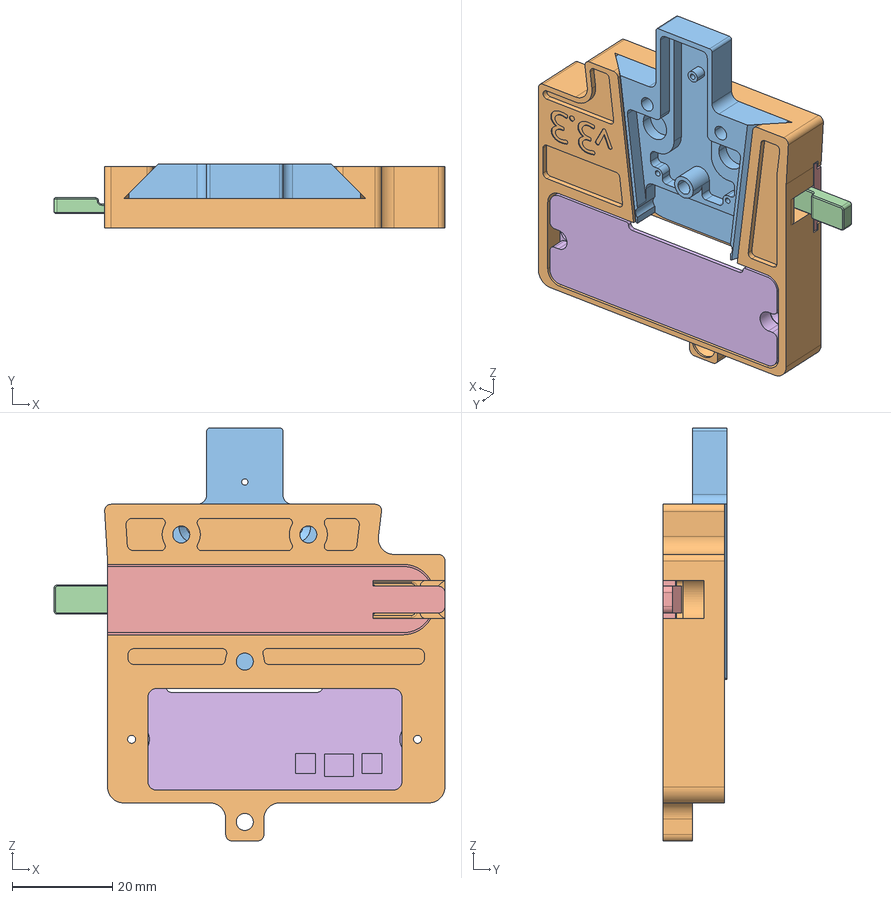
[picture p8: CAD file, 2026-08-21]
sUPI Mechanicals/19200_13122513_asm_v3-3.stp
78.1 x 12.7 x 82.5 mm

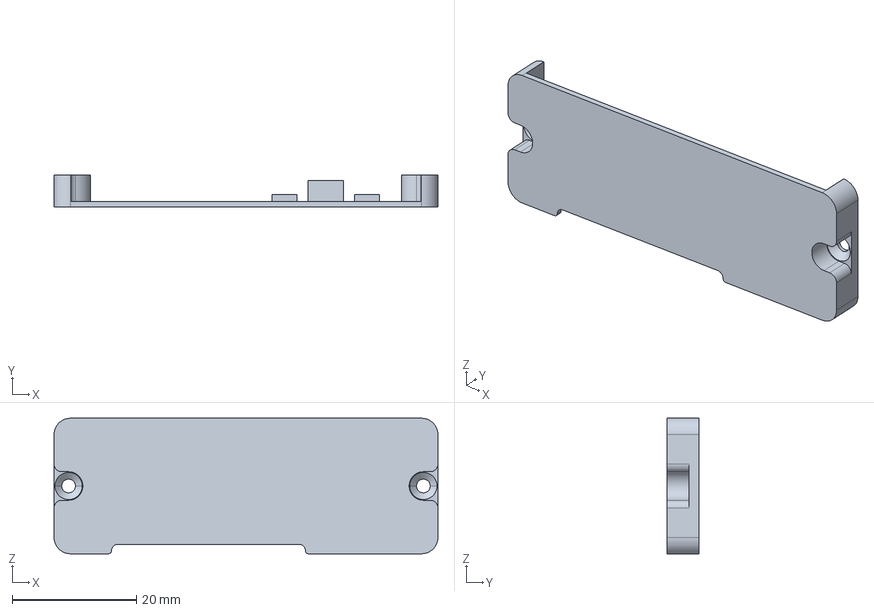
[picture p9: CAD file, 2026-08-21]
sUPI Mechanicals/19200_13122517_v3-3.stp
61.8 x 5.18 x 21.8 mm

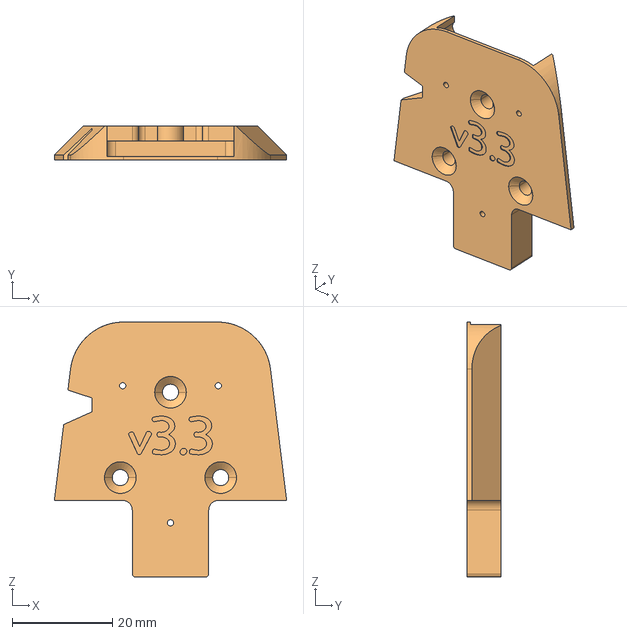
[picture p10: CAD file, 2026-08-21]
sUPI Mechanicals/19200_13122518_v3-3.stp
46.3 x 6.86 x 50.8 mm

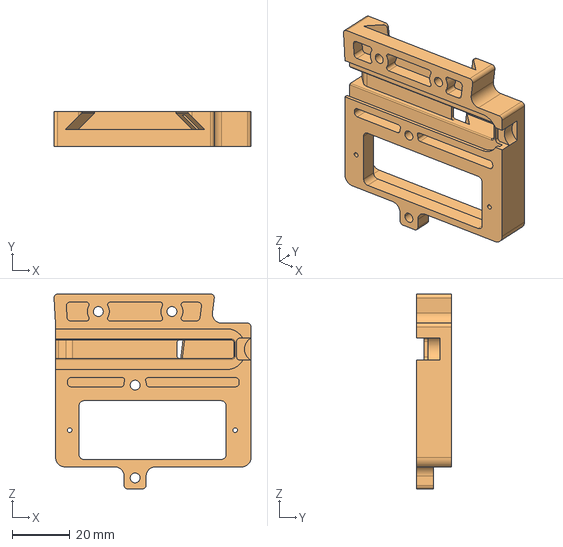
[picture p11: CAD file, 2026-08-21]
sUPI Mechanicals/19200_13122514_v3-3.stp
68.0 x 12.2 x 67.3 mm

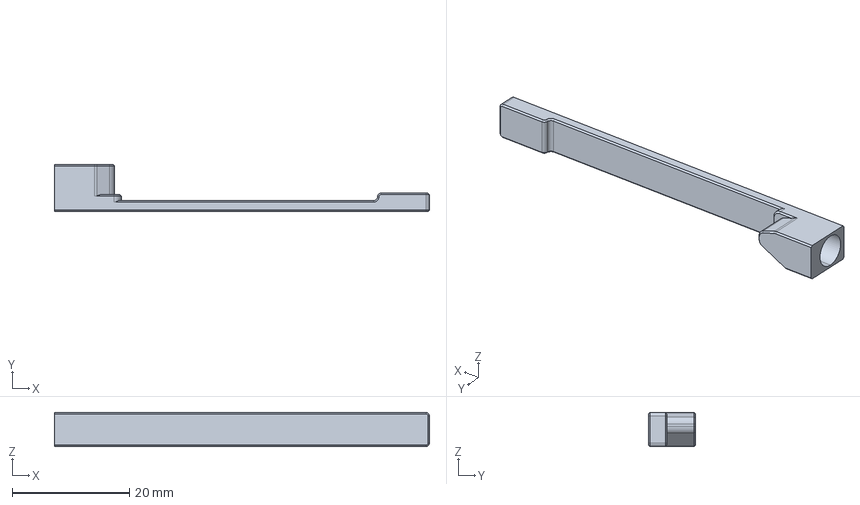
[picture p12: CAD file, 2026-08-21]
sUPI Mechanicals/19200_13122515_v3-3.stp
64.0 x 8.10 x 5.84 mm

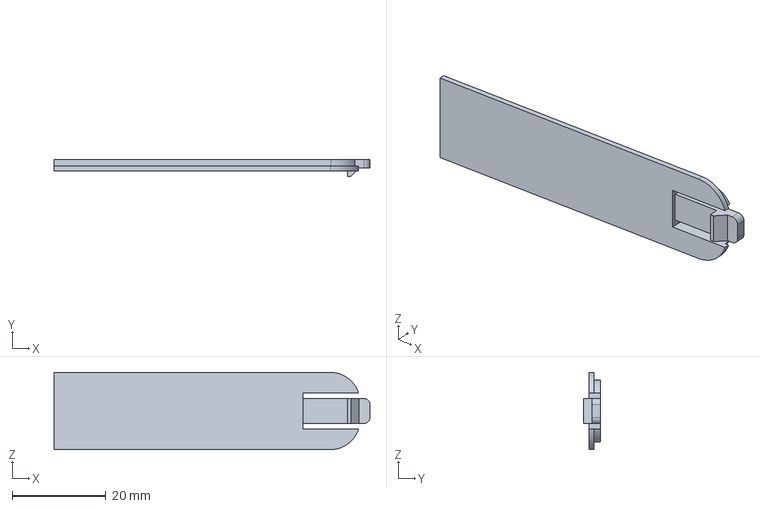
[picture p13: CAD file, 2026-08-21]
sUPI Mechanicals/19200_13122516_v3-3.stp
67.4 x 3.62 x 16.5 mm

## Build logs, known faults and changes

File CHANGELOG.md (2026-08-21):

# sUPI — Change Log

**Small Universal Payload Interface**

> **DISTRIBUTION STATEMENT A. APPROVED FOR PUBLIC RELEASE; DISTRIBUTION IS UNLIMITED.**

Design change history for the sUPI mechanical interface. Entries are reproduced verbatim from the
source document; part nomenclature in the Part column was added for readability and is not part of
the original text.

---

## sUPI 3.1

| Part | Change |
| --- | --- |
| — | Initial DEVCOM AC baseline release. |

---

## sUPI 3.2

| Part | Change |
| --- | --- |
| `19200_13122514.prt` — V-Mount Base | Changed to be machinable without custom dovetail cutter. |

<table>
<tr><td align="center"><strong>Old</strong></td><td align="center"><strong>New</strong></td></tr>
<tr>
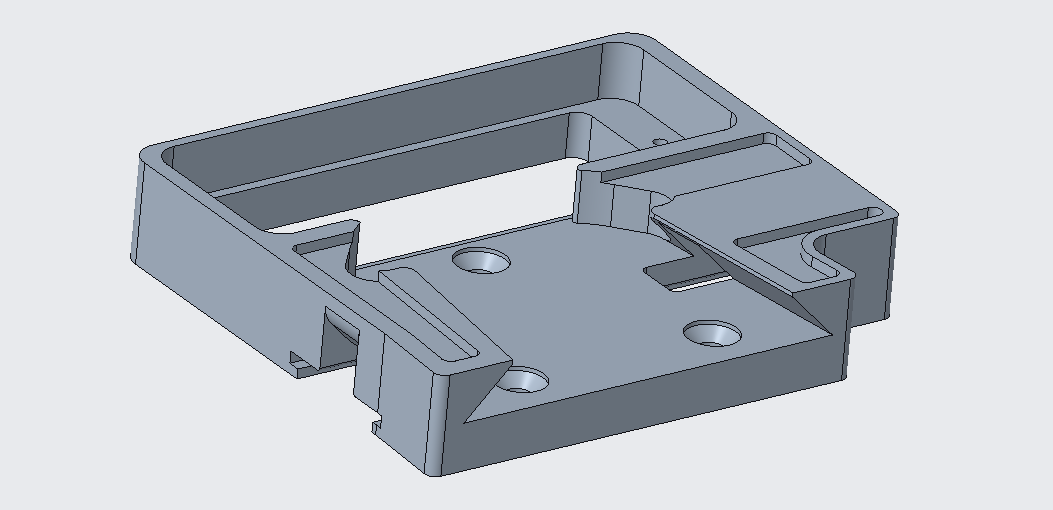
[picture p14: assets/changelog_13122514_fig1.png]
13122514 before the 3.2 change
<td></td>
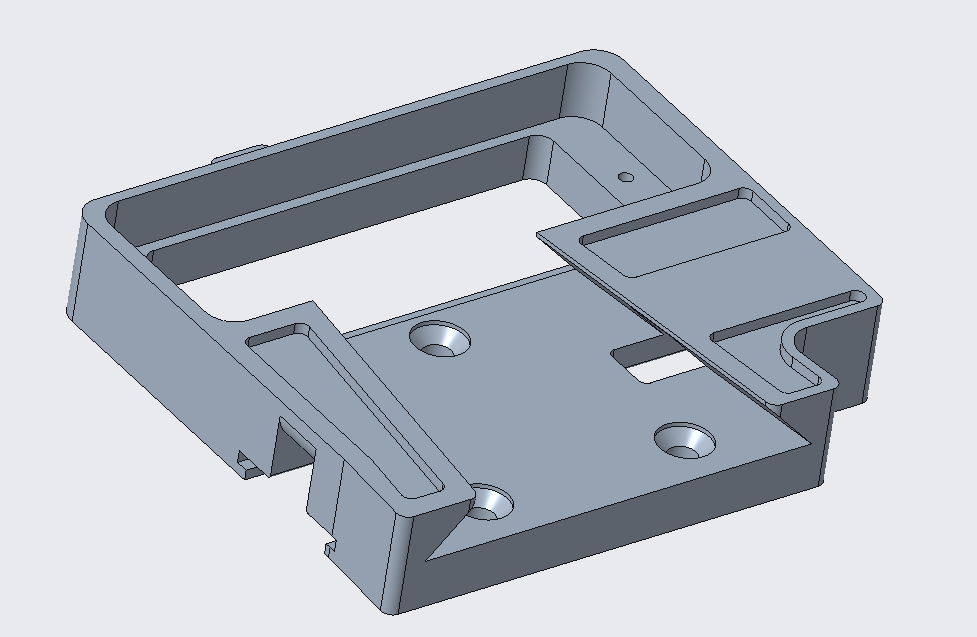
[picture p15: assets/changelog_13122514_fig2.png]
13122514 after the 3.2 change
<td></td>
</tr>
</table>

**`13122514` before and after the v3.2 change.** Labels and figure placement are as given in the
source document.

---

## sUPI 3.3

Manufacturability and fit. Removes special tooling from the machining plan and takes slop out of the
mating stack. **No electrical interface changes.**

| Part | Change |
| --- | --- |
| `13122514` — V-Mount Base | Offset taper faces to eliminate play between parts. |
| `13122514` — V-Mount Base | Changed button cover slot to rounded interior to make it machinable. |
| `13122516` — Small Button Cover | Rounded button cover to match `13122514` slot round. |
| `13122515` — Short Button | Changed button geometry to make lower profile and eliminate bending. |
| `13122515` — Short Button | Changed button interfaces to eliminate play between parts. |
| Payload and platform interfaces | Added version number engraving. |

The engraving means **v3.3 hardware is physically marked.** Check the engraved version number
before mating mixed-vintage halves — earlier parts have looser fit, and earlier `13122515` buttons
have the taller profile that was prone to bending.

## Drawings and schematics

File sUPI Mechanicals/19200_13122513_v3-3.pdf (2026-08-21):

D
D

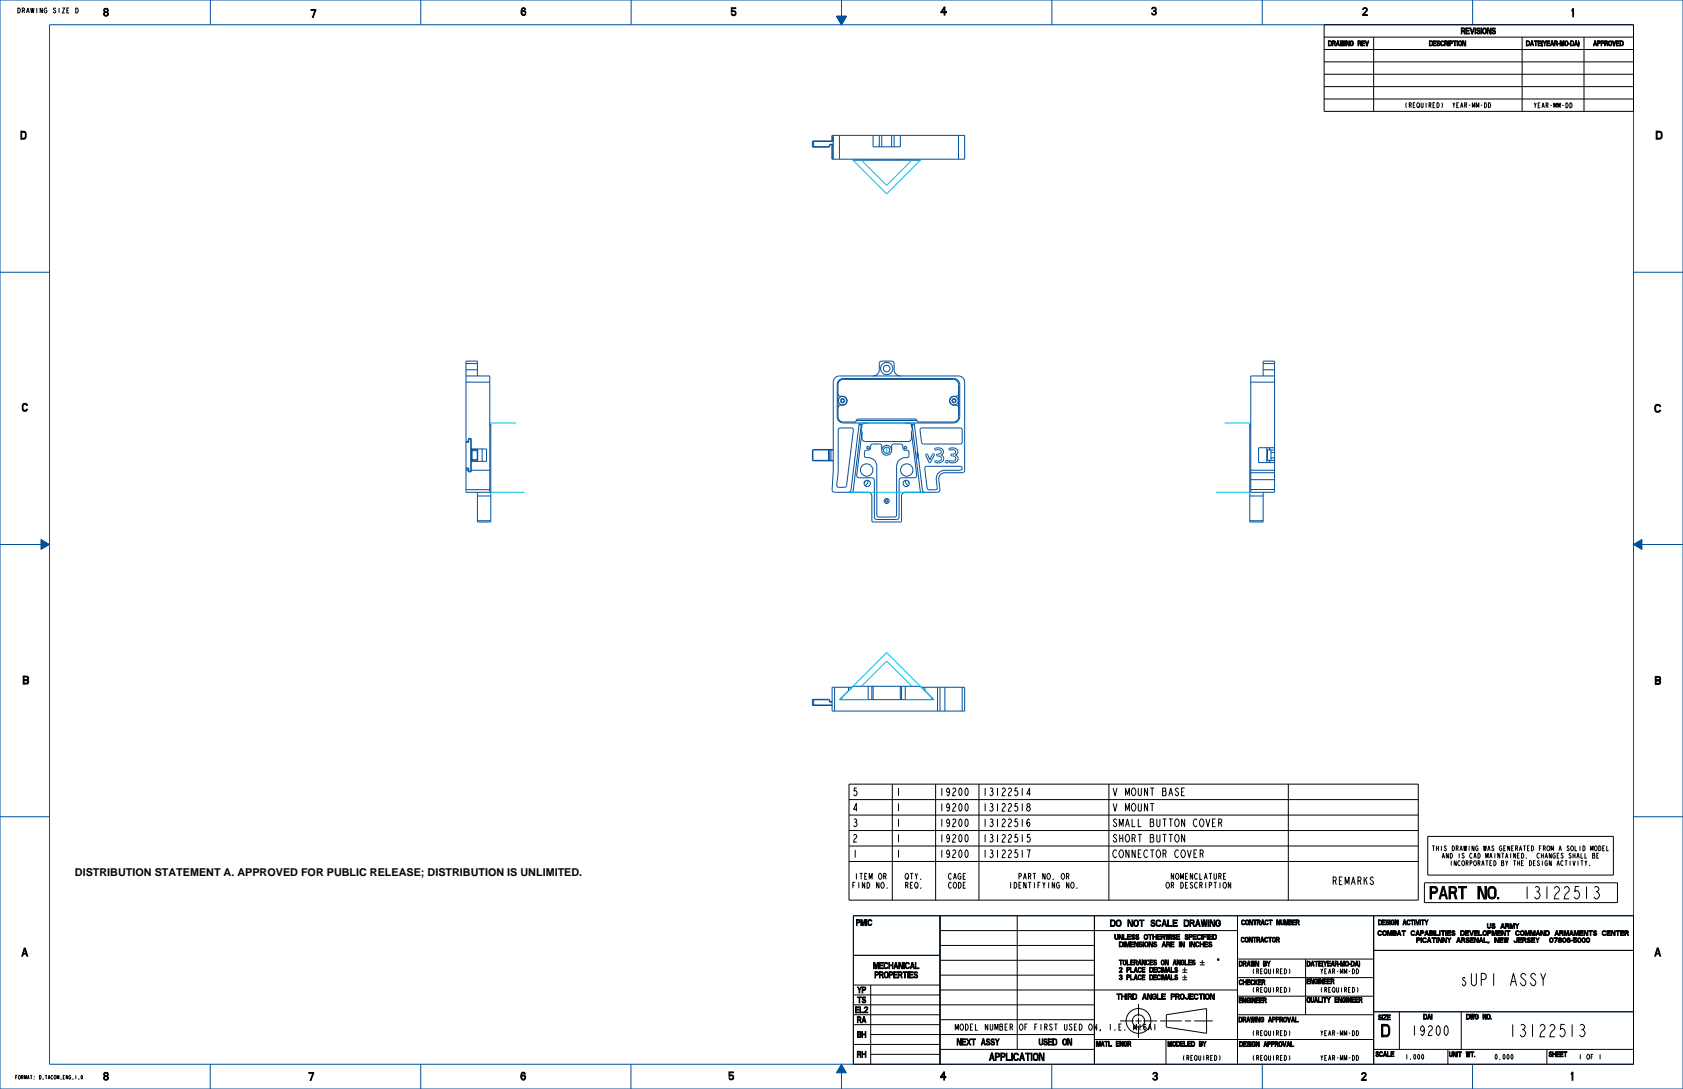
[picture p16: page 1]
DESIGN ACTIVITY; SIZE; DAI; SCALE; UNIT WT.; DRAWN; DATE(YEAR-MO-DA); CHECKER; ENGINEER; QUALITY; DRAWING APPROVAL; MATL ENGR; MODELED; DESIGN APPROVAL; CONTRACT; NUMBER; CONTRACTOR; SHEET; DRAWING SIZE D; PLACE; DECIMALS; FORMAT: D_TACOM_ENG_1_0; DWG NO.; SMALL BUTTON COVER; REVISIONS; DRAWING; REV; DESCRIPTION; APPROVED; (REQUIRED) YEAR-MM-DD; YEAR-MM-DD; sUPI ASSY; US ARMY; COMBAT; CAPABILITIES; DEVELOPMENT COMMAND; ARMAMENTS CENTER; PICATINNY ARSENAL,; NEW JERSEY 07806-5000; (REQUIRED)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

5 | 1 | 19200 | 13122514 | V MOUNT BASE
4 | 1 | 19200 | 13122518 | V MOUNT
2 | 1 | | 19200 | | 13122515 | | SHORT BUTTON
1 | | 1 | | 19200 | | 13122517 | | CONNECTOR COVER
ITEM OR FIND NO. | QTY. REQ. | CAGE CODE | PART NO. OR IDENTIFYING NO. | OR DESCRIPTION | REMARKS NOMENCLATURE

THIS DRAWING WAS GENERATED FROM A SOLID MODEL
INCORPORATED BY THE DESIGN ACTIVITY.
PART NO. 13122513

DISTRIBUTION STATEMENT A. APPROVED FOR PUBLIC RELEASE; DISTRIBUTION IS UNLIMITED.

DO NOT SCALE DRAWING
UNLESS OTHERWISE SPECIFIED
TOLERANCES ON ANGLES

(REQUIRED) | YEAR-MM-DD
(REQUIRED) | (REQUIRED)

YP
TS
EL2
RA

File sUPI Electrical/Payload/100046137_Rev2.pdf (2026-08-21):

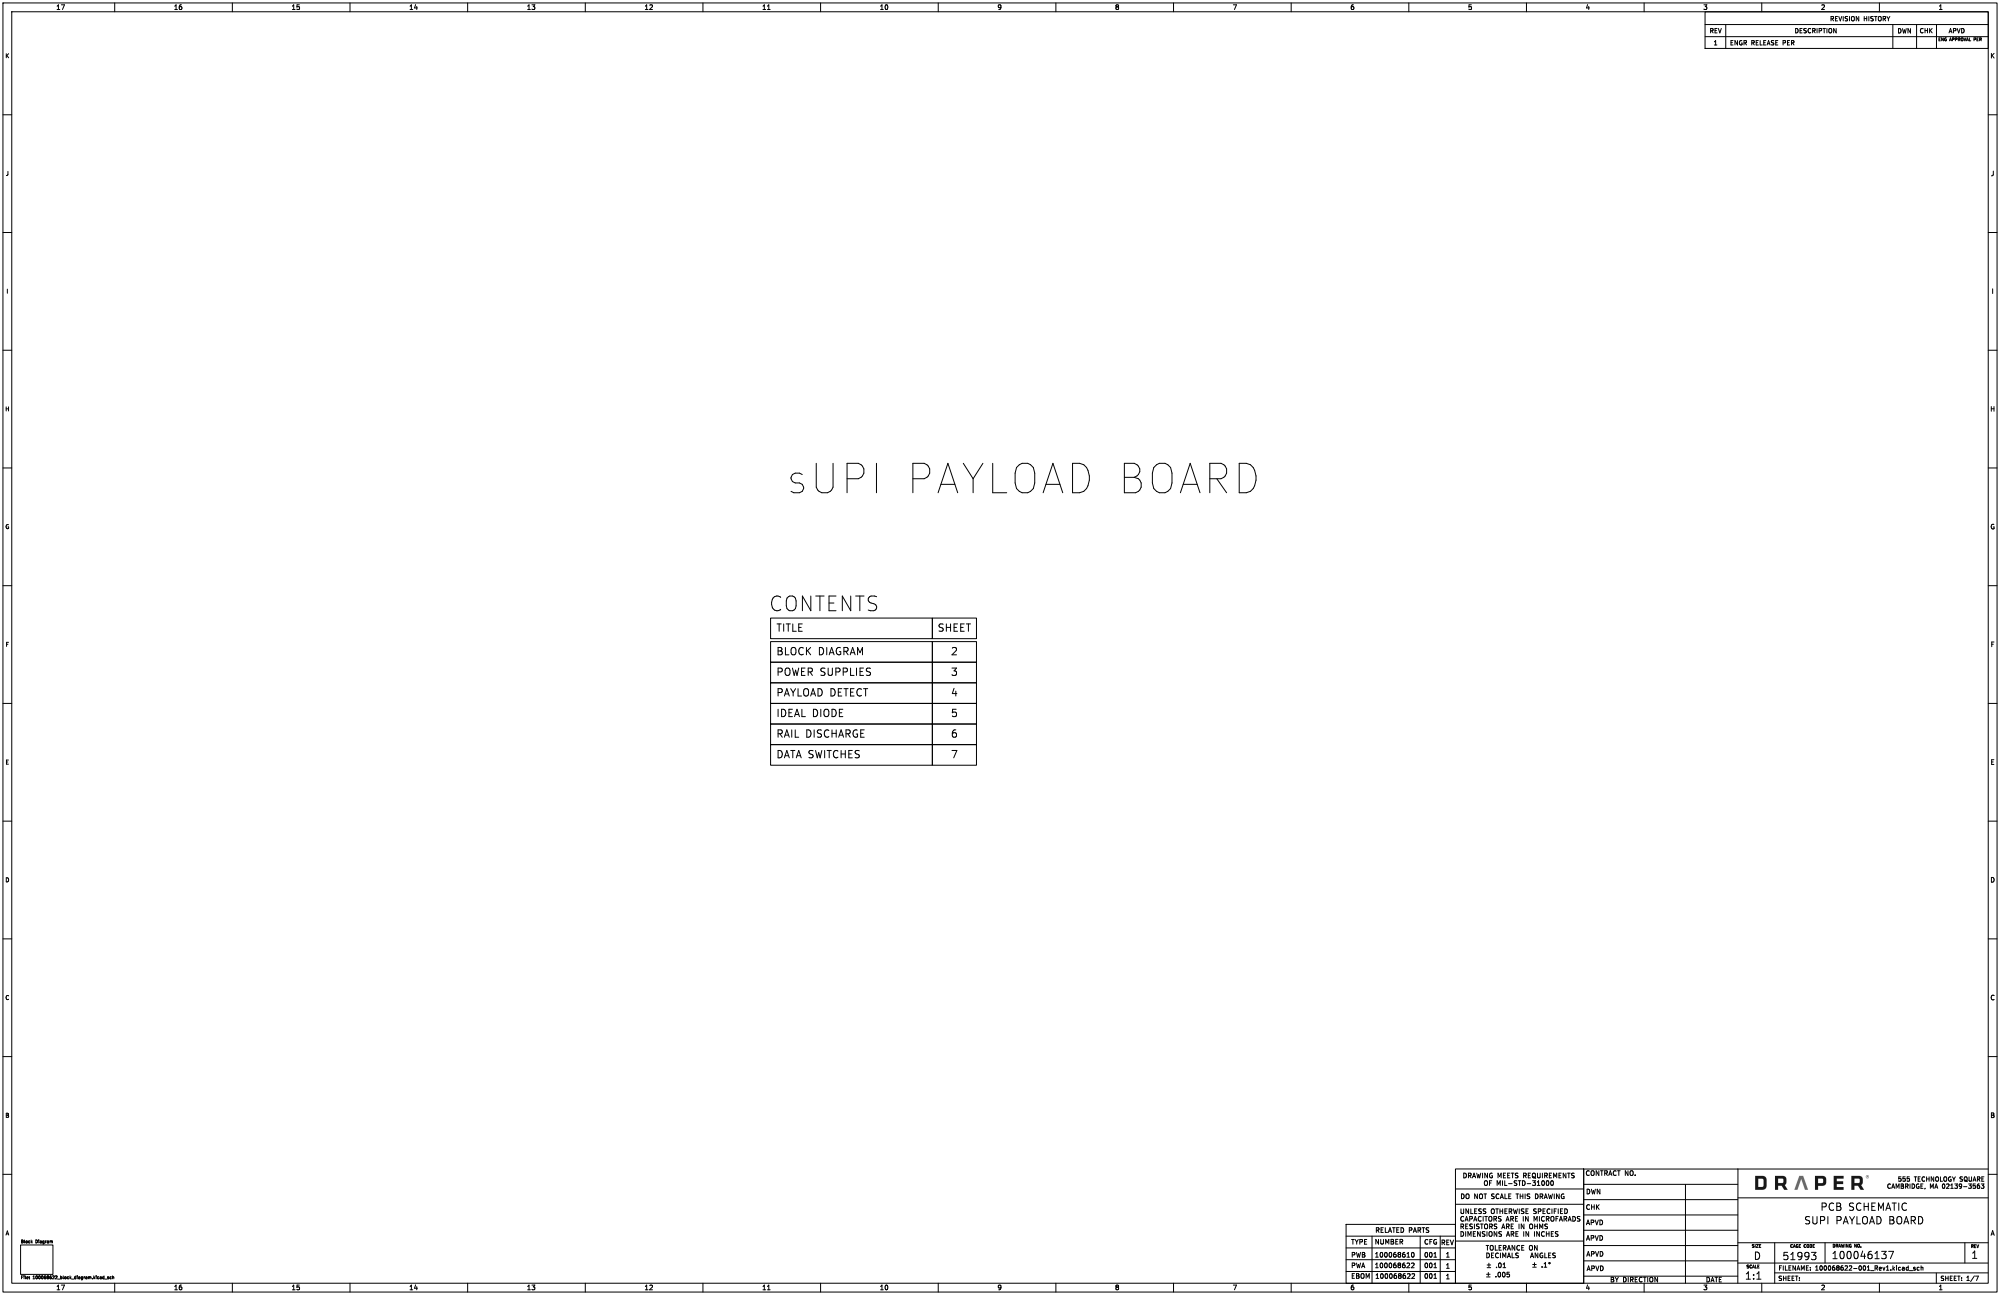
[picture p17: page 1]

DWN

CHK

CAPACITORS ARE IN MICROFARADS

APVD

RELATED PARTS

TYPE | CFG

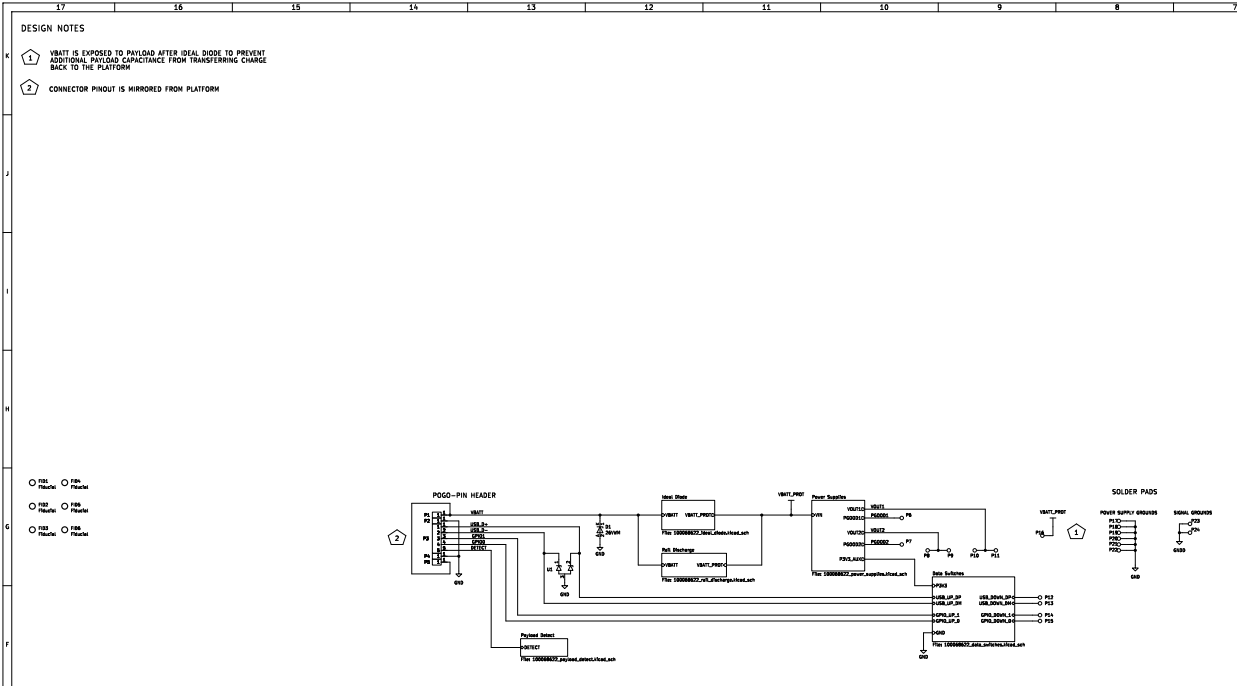
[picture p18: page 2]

VBATT IS EXPOSED TO PAYLOAD AFTER IDEAL DIODE TO PREVENT
ADDITIONAL PAYLOAD CAPACITANCE FROM TRANSFERRING CHARGE
BACK TO THE PLATFORM

POWER SUPPLY GROUNDS SOLDER PADS

THIS DOCUMENT IS SUBJECT TO THE RESTRICTIONS ON SHEET 1 OF THIS DOCUMENT.

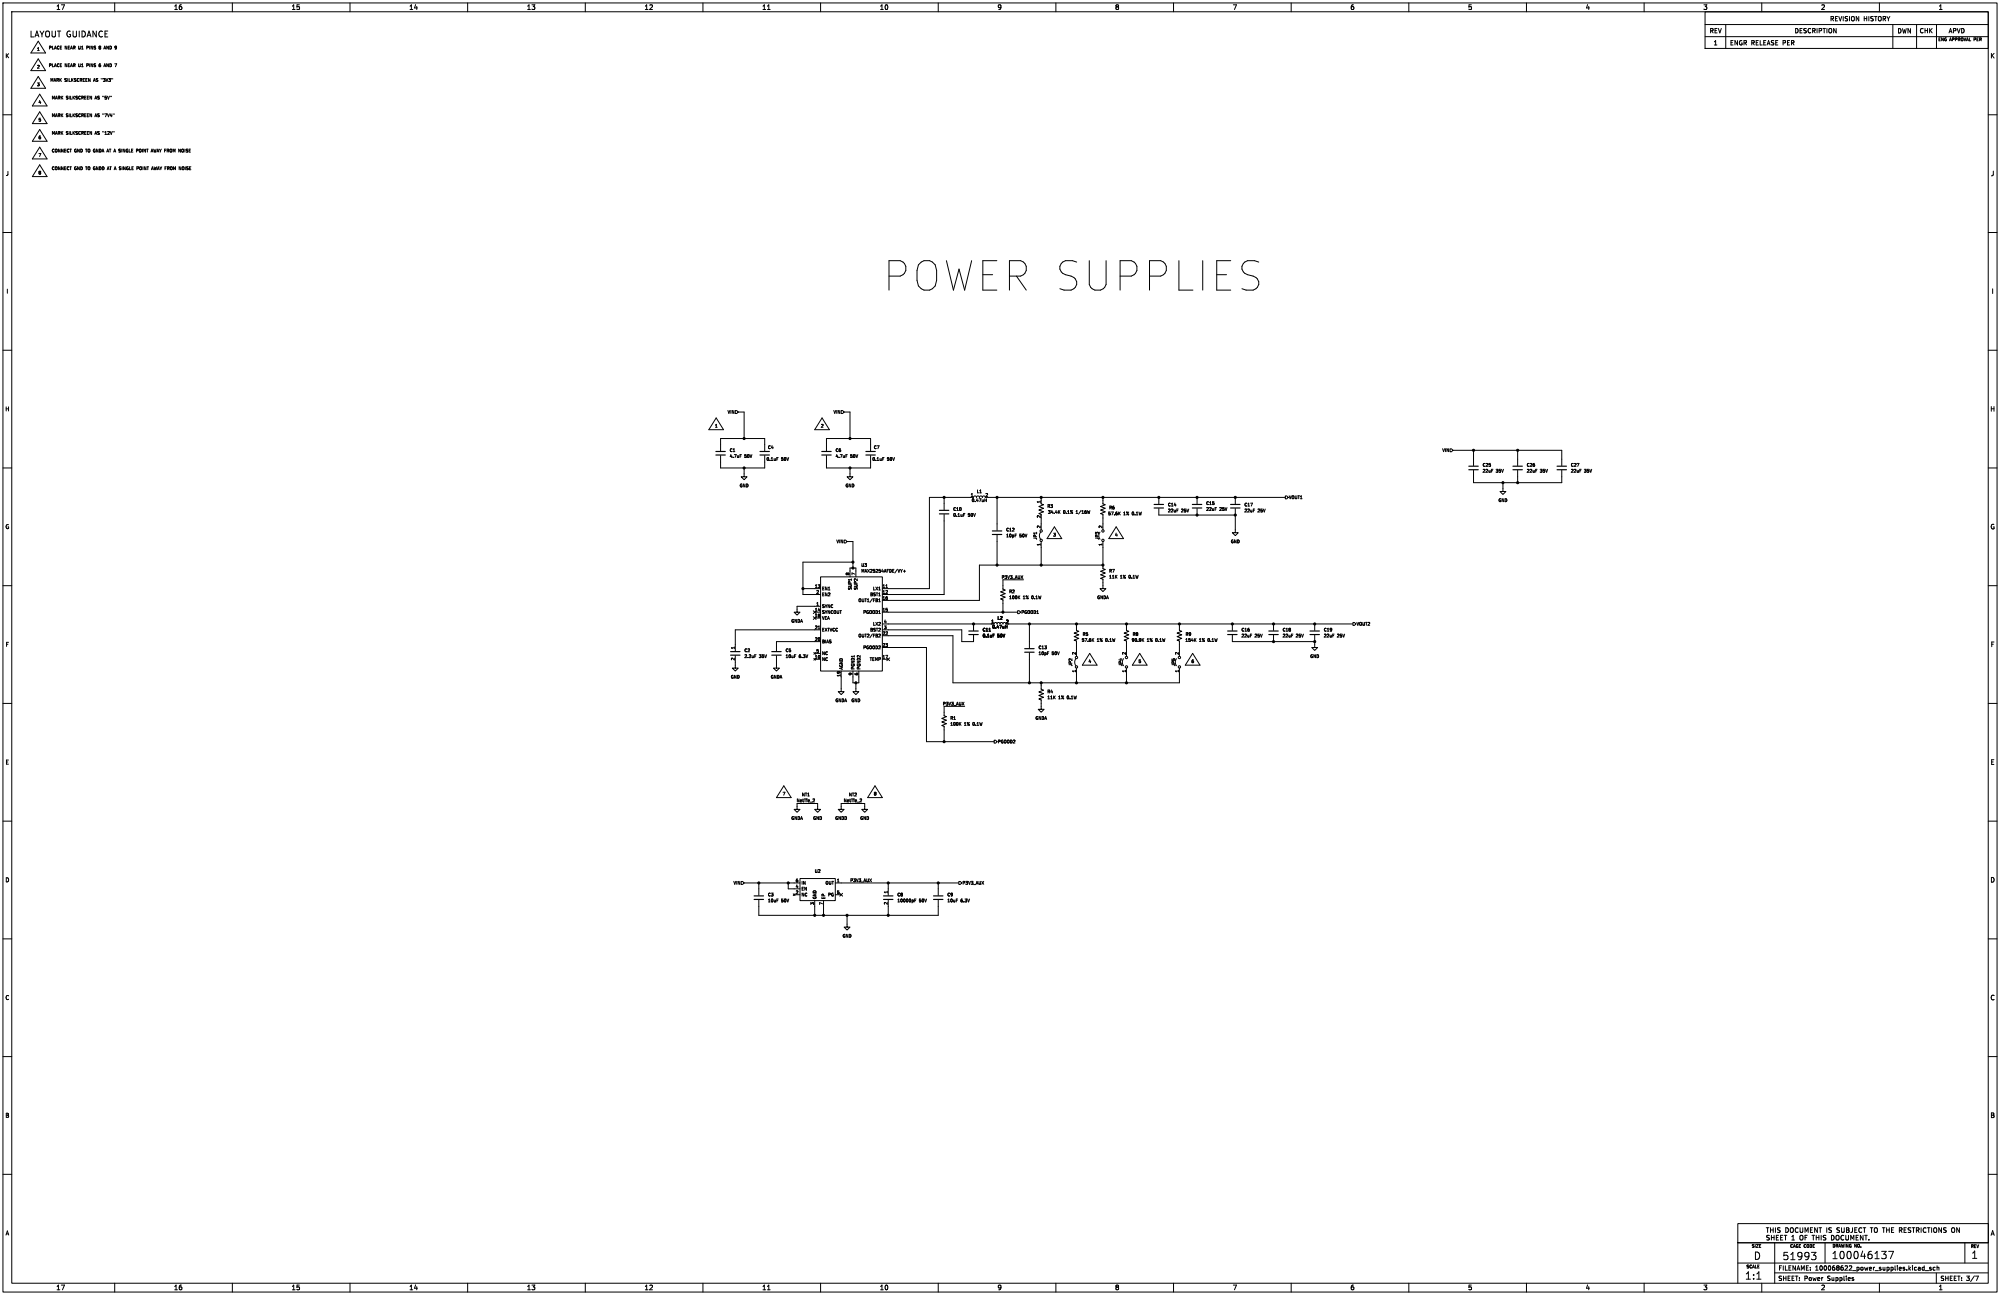
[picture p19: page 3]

CONNECT GND TO GNDA AT A SINGLE POINT AWAY FROM NOISE CONNECT GND TO GNDD AT A SINGLE POINT AWAY FROM NOISE

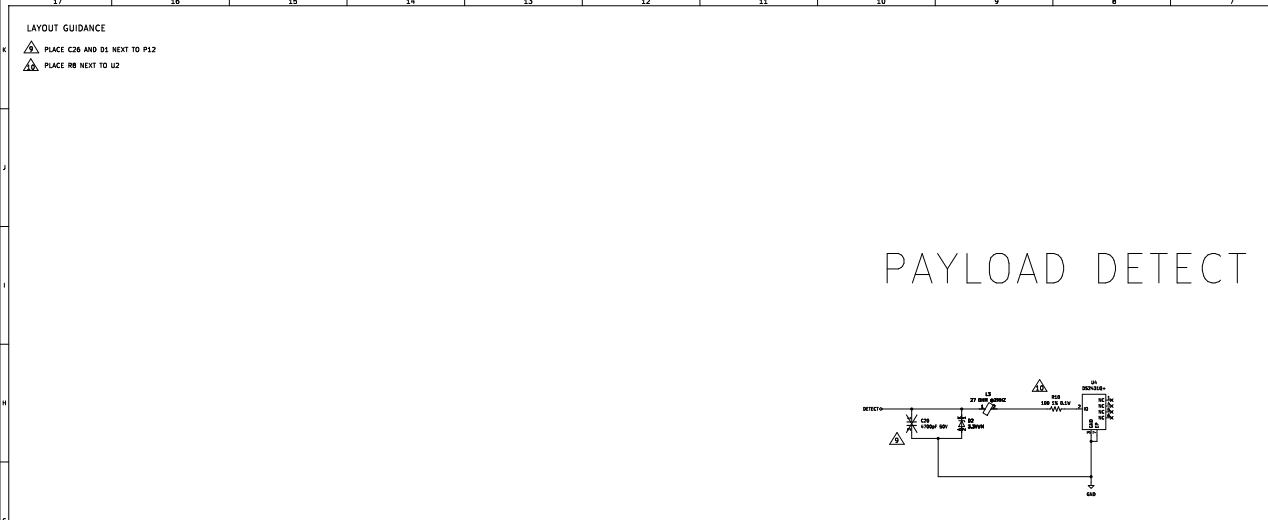
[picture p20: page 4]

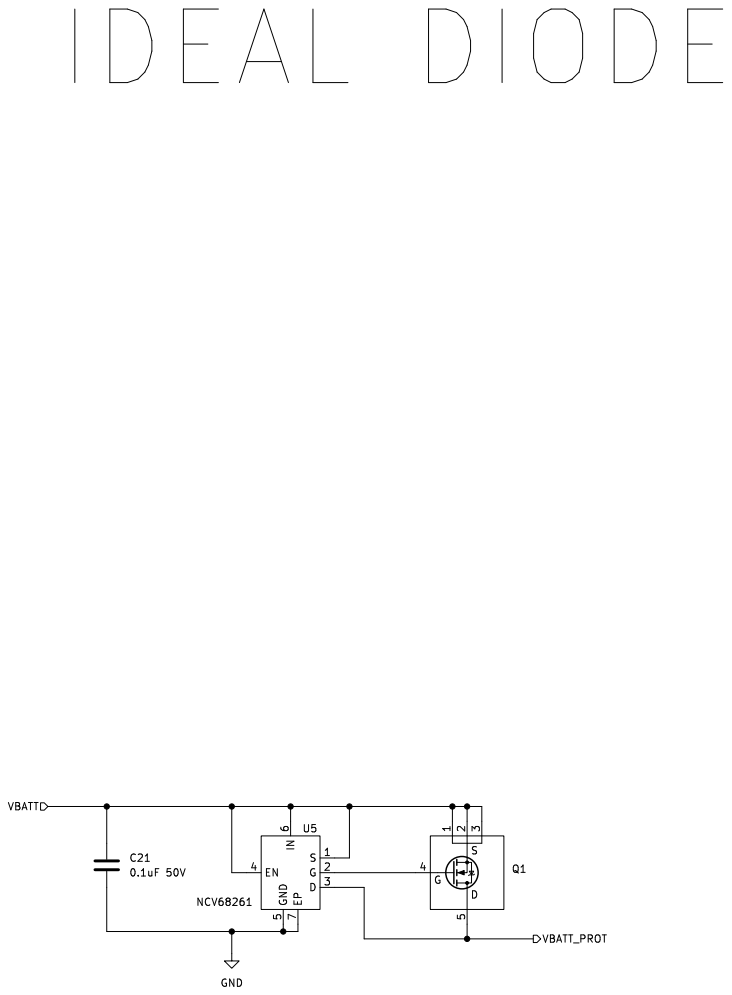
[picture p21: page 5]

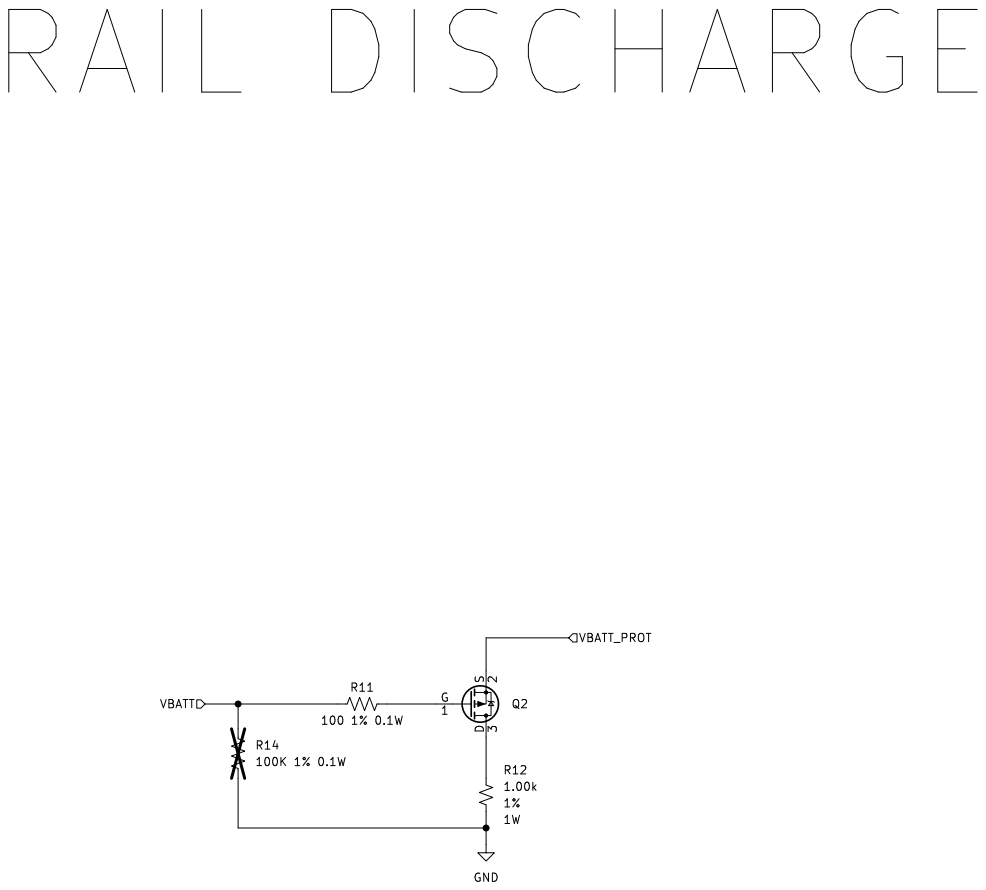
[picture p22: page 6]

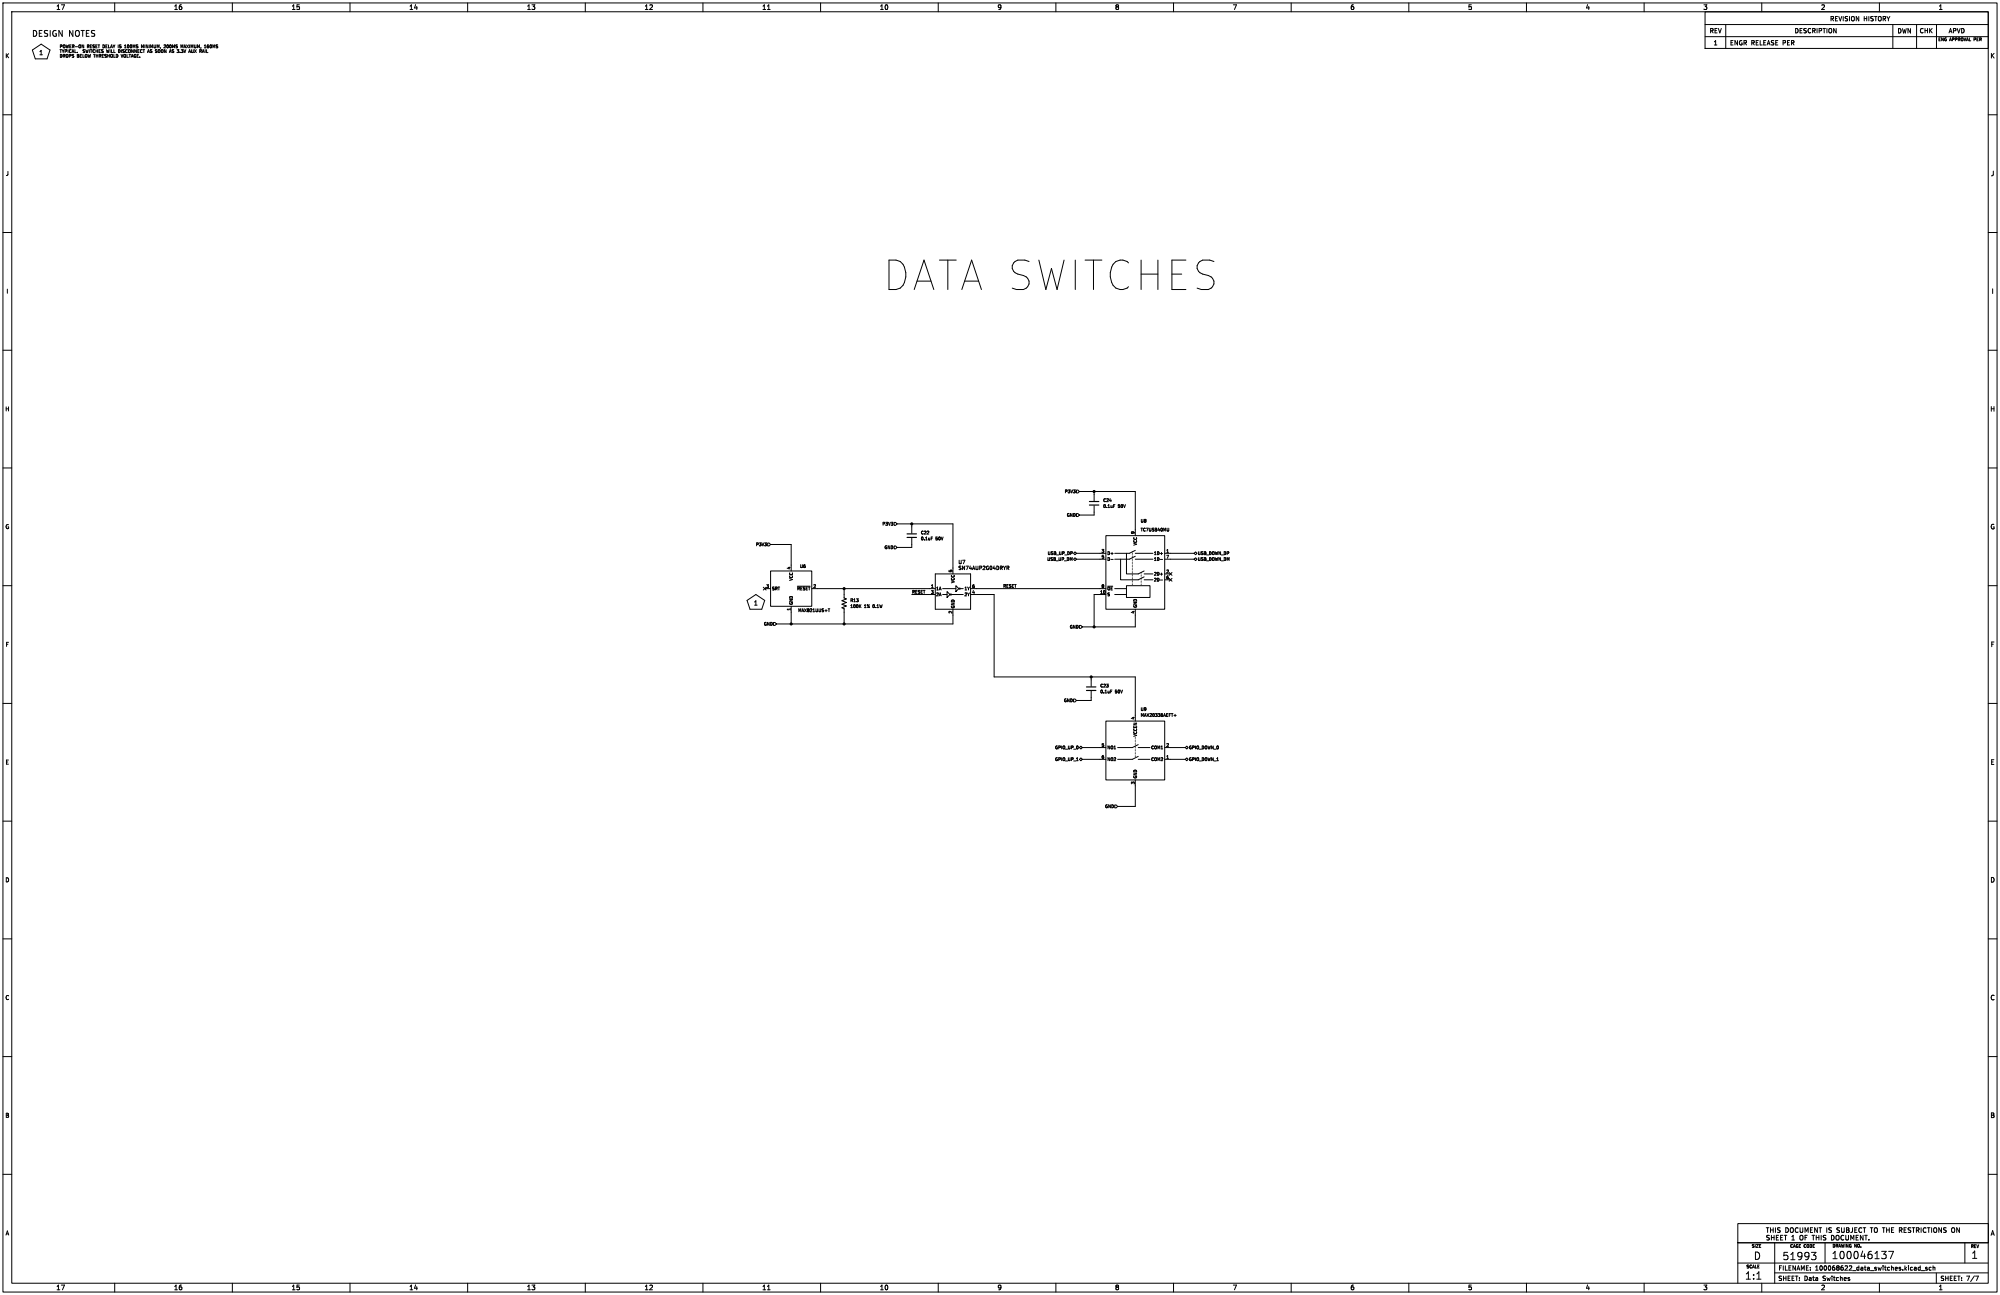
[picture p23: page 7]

POWER-ON RESET DELAY IS 100MS MINIMUM, 200MS MAXIMUM, 160MS

TYPICAL. SWITCHES WILL DISCONNECT AS SOON AS 3.3V AUX RAIL DROPS BELOW THRESHOLD VOLTAGE. 1

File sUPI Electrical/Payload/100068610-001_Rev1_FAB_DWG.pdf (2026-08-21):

## LAYER STACKUP AND FILENAME

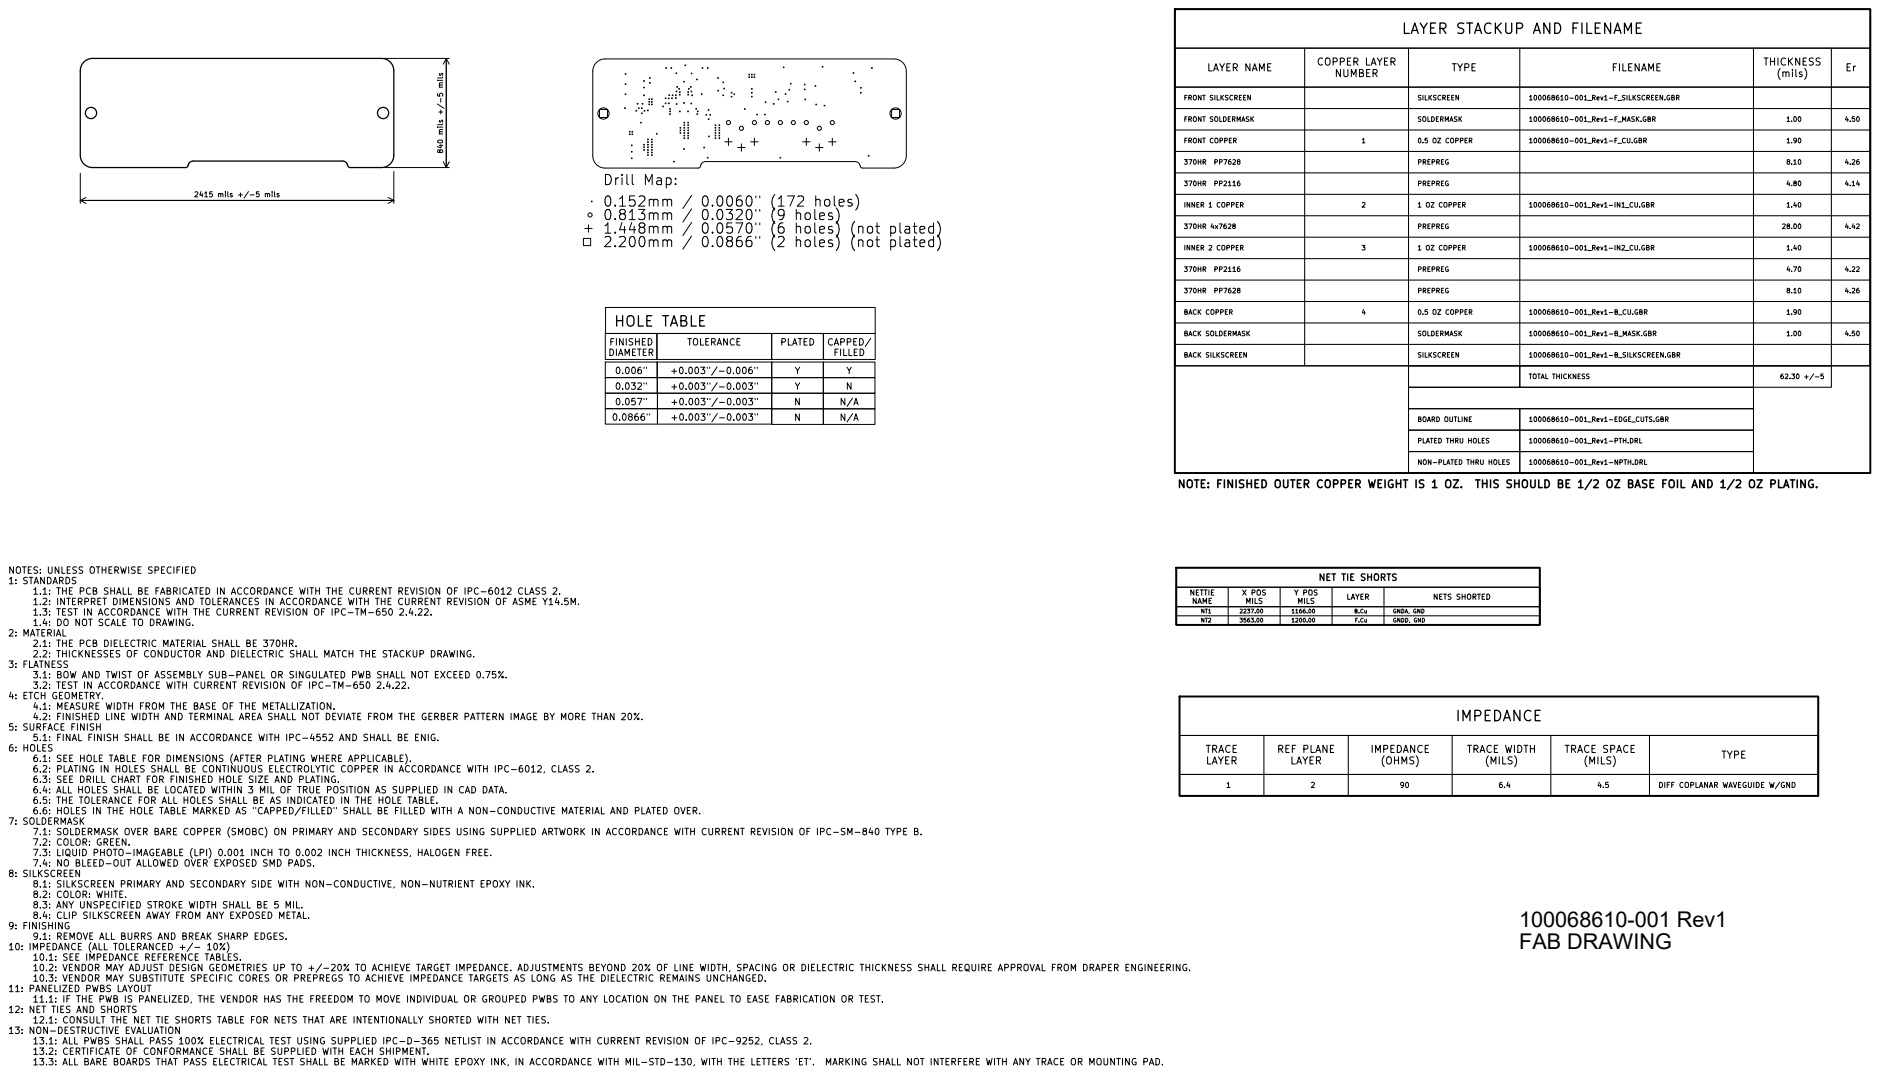
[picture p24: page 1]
100068610-001_Rev1-B_SILKSCREEN.GBR; 6.4 TRACE WIDTH (MILS); DIFF COPLANAR WAVEGUIDE W/GND TRACE; LAYER; NETS SHORTED; FRONT SILKSCREEN; PREPREG NOTE:; FINISHED OUTER COPPER; WEIGHT IS 1 OZ.; THIS SHOULD BE 1/2; BASE FOIL AND 1/2; OZ PLATING.; IMPEDANCE; TOTAL THICKNESS; 100068610-001_Rev1-PTH.DRL; GNDD, GND; LAYER NAME; SILKSCREEN REF PLANE; GNDA, GND; 4.50 TYPE; 1: STANDARDS; THE PCB SHALL BE FABRICATED IN ACCORDANCE WITH THE CURRENT REVISION OF IPC-6012; CLASS 2. 1.2: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

370HR 4x7628 FRONT SOLDERMASK | 3 | SOLDERMASK TYPE | 100068610-001_Rev1-F_MASK.GBR | 28.00 THICKNESS | Er 4.50
FRONT COPPER | 4 1 | 0.5 OZ COPPER | FILENAME 100068610-001_Rev1-F_CU.GBR | 1.90

100068610-001_Rev1-F_SILKSCREEN.GBR COPPER LAYER
NUMBER

370HR PP7628 | | PREPREG | | (mils) 1.00 CAPPED/ FILLED 8.10 | 4.26

INNER 1 COPPER | 2 | 1 OZ COPPER | 100068610-001_Rev1-IN1_CU.GBR | 1.40

PREPREG | | | 4.42

INNER 2 COPPER | | 1 OZ COPPER | 100068610-001_Rev1-IN2_CU.GBR | 1.40

PREPREG | | 4.70 | 4.22

BACK COPPER | | 0.5 OZ COPPER | 100068610-001_Rev1-B_CU.GBR | 1.90 | 4.26 BACK SILKSCREEN

PREPREG | | 8.10

BACK SOLDERMASK | | | 100068610-001_Rev1-B_MASK.GBR | 1.00

SOLDERMASK NON-PLATED THRU HOLES

100068610-001_Rev1-EDGE_CUTS.GBR NOTES: UNLESS OTHERWISE SPECIFIED

BOARD OUTLINE
2 NET TIE SHORTS

PLATED THRU HOLES

(OHMS) Y POS MILS NETTIE NAME

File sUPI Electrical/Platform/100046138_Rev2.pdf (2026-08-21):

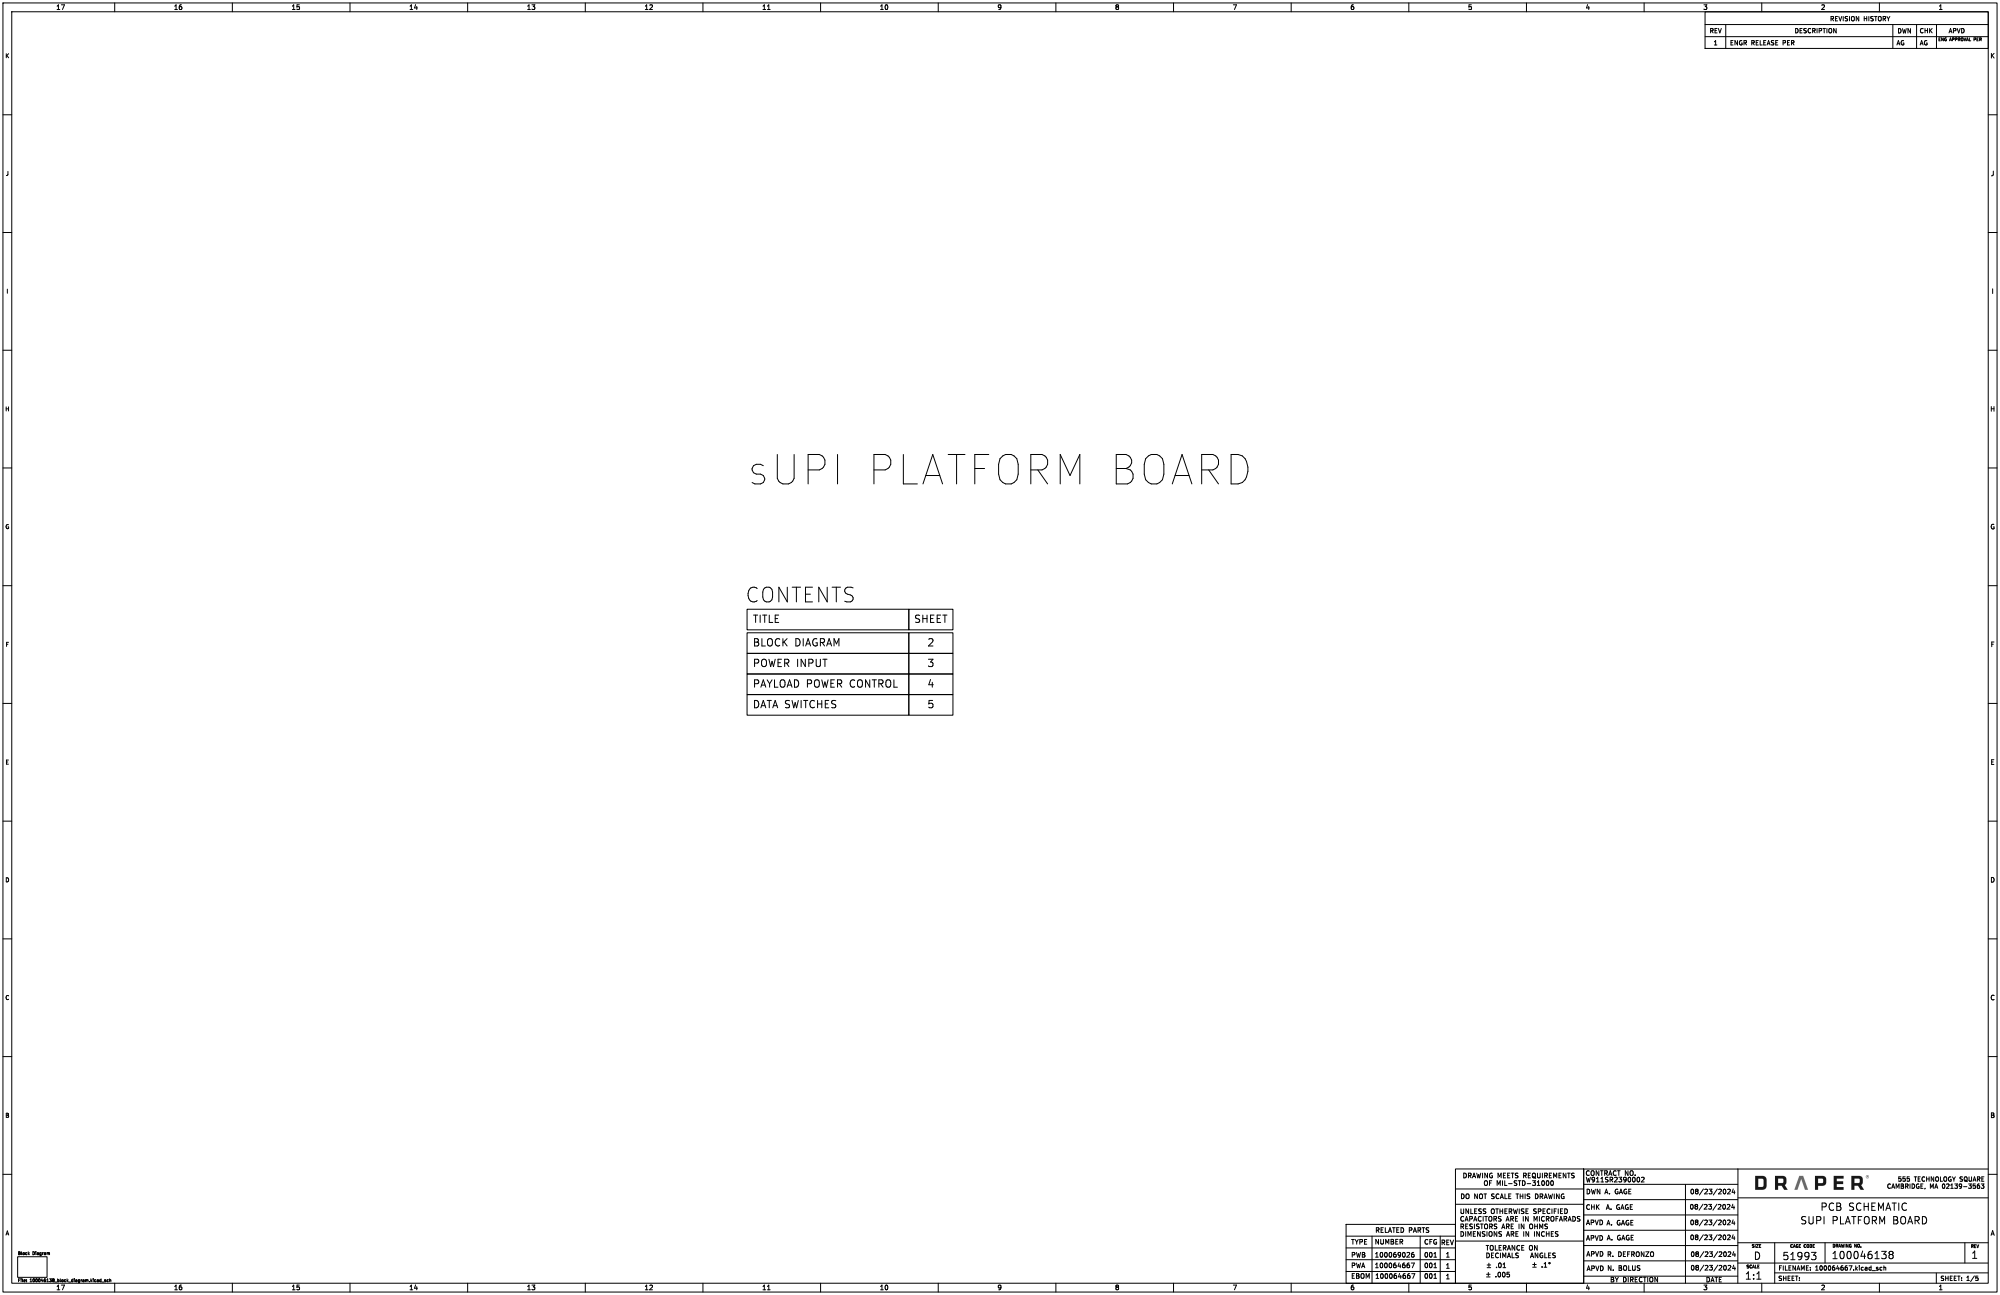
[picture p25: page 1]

APVD
CAPACITORS ARE IN MICROFARADS

TYPE | NUMBER | CFG | REV

08/23/2024

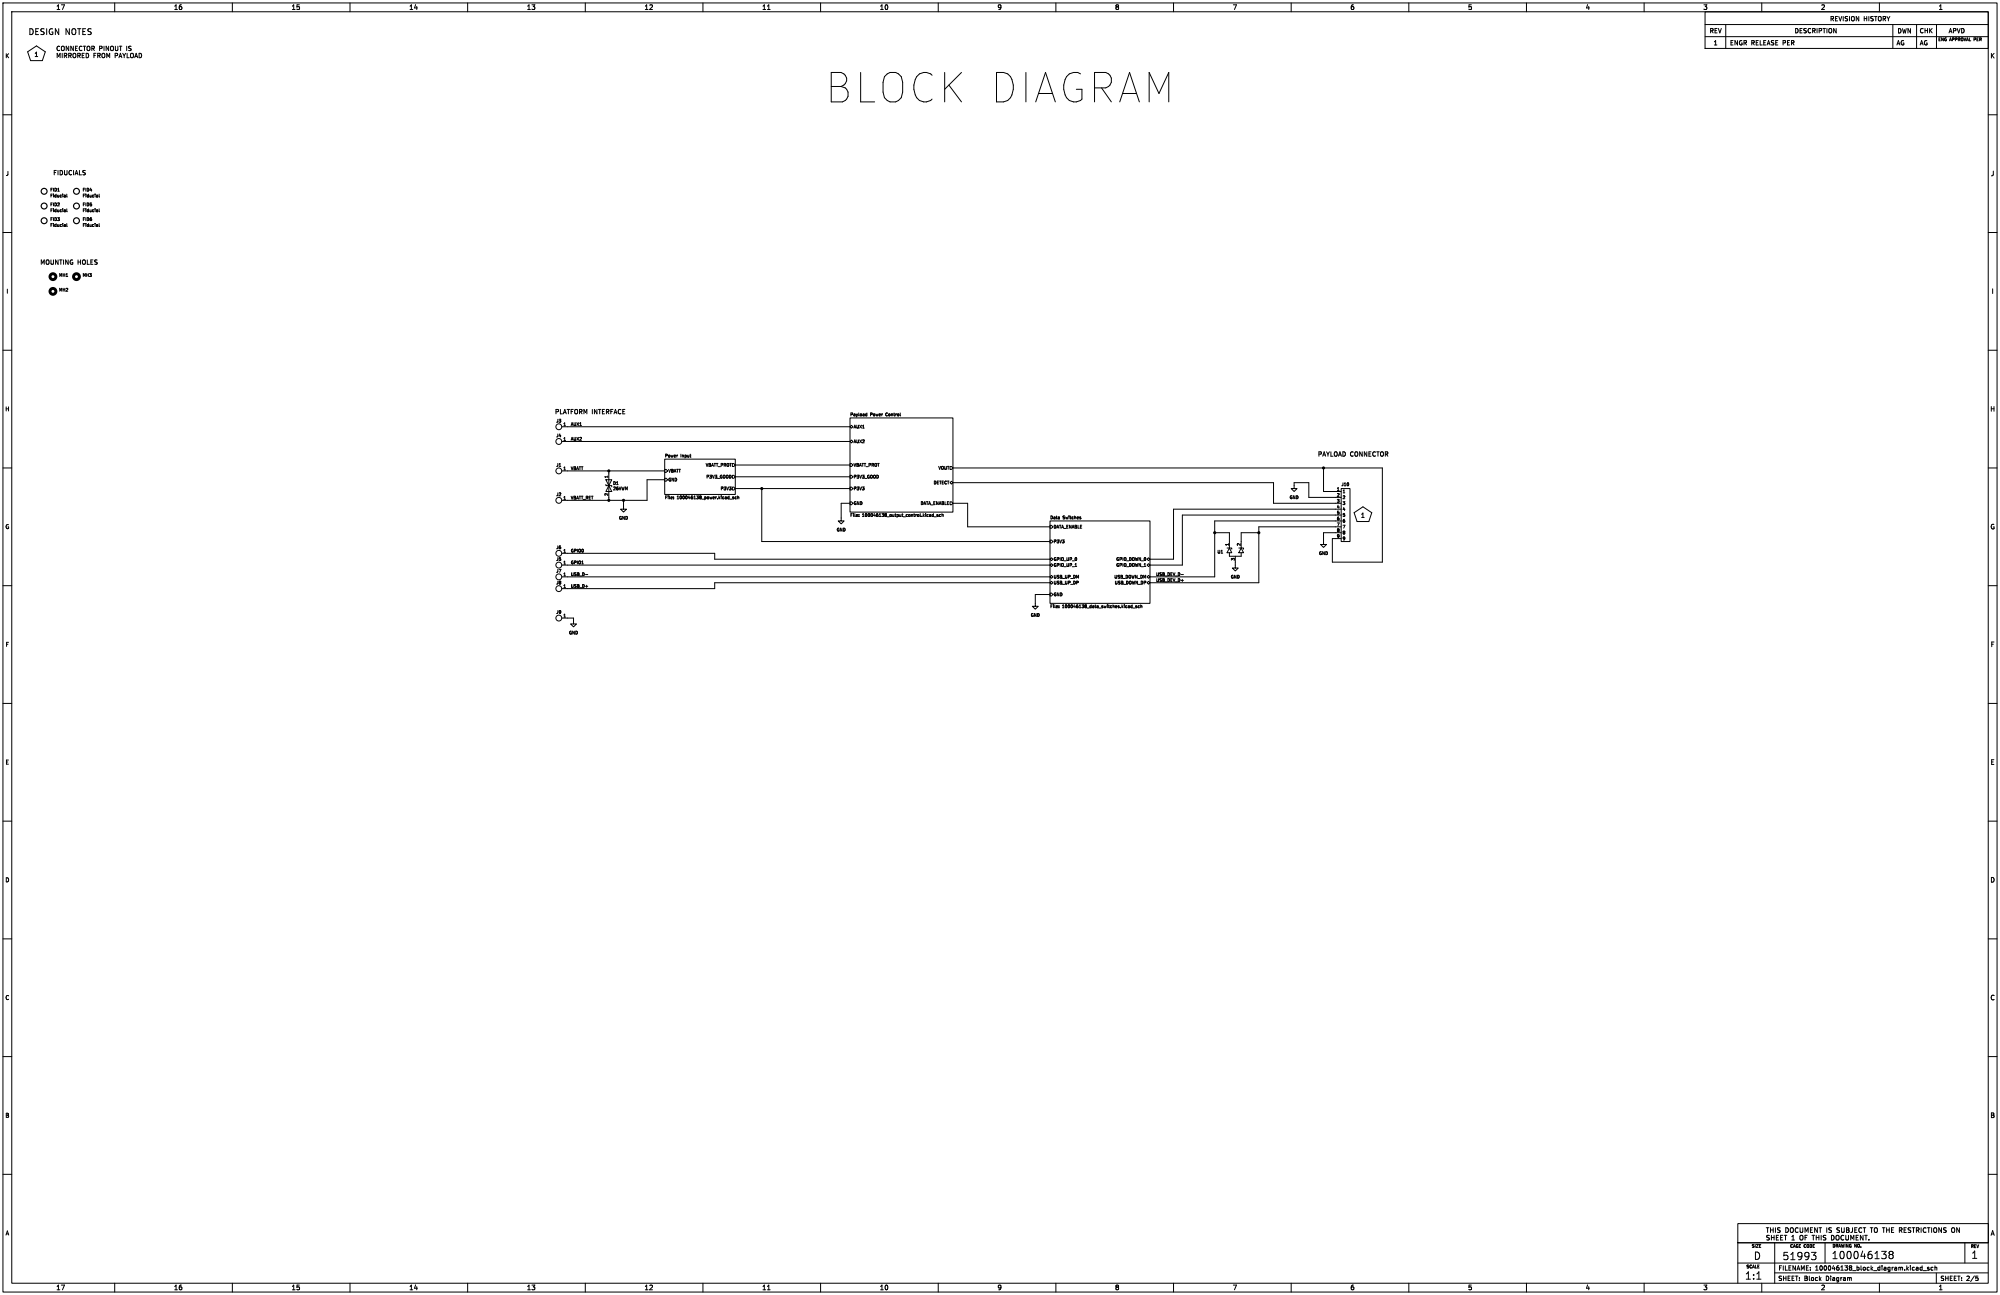
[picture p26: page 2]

THIS DOCUMENT IS SUBJECT TO THE RESTRICTIONS ON SHEET 1 OF THIS DOCUMENT.

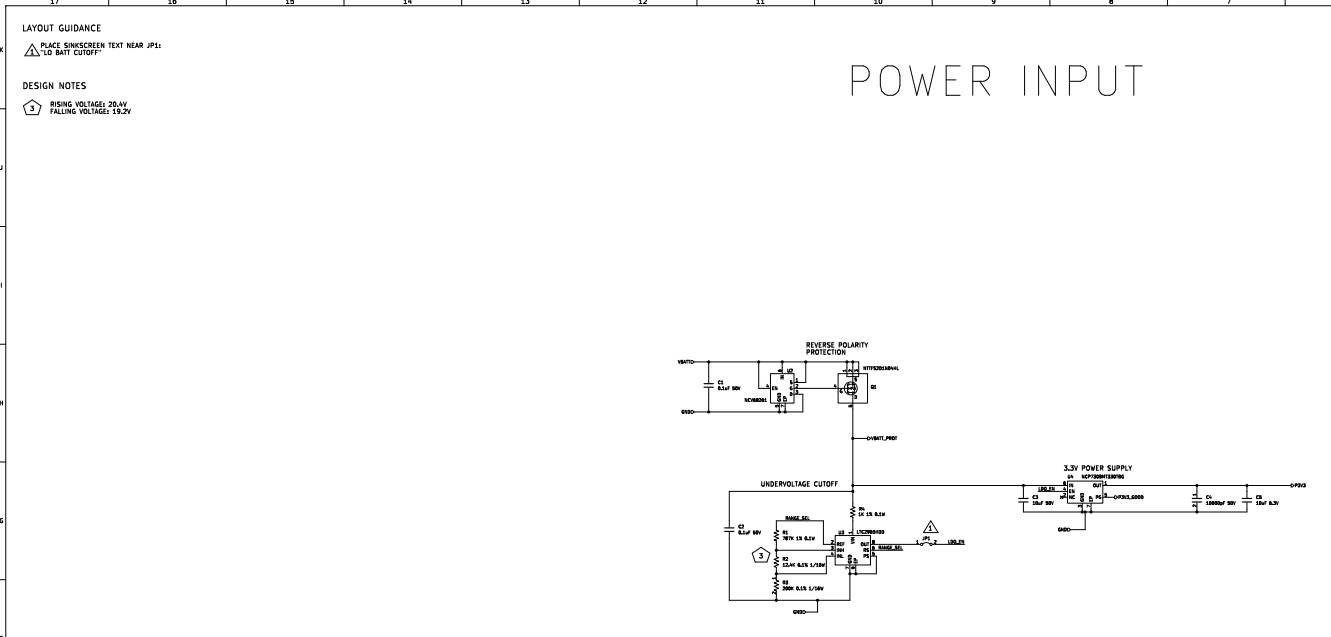
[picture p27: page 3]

PLACE SINKSCREEN TEXT NEAR JP1:
1 "LO BATT CUTOFF"


PLACE SILKSCREEN BETWEEN JP2 AND JP3:
"SELECT"

PLACE C26 AND D1 NEXT TO J11

PLACE U8 NEXT TO J4 AND J5

PLACE R19 AND R20 NEXT TO U4

AUX PINS COULD BE USART1 OR I2C1 FOR COMMUNICATION
WITH THE HOST PLATFORM. SERIES RESISTORS ON AUX SIGNALS
ARE INTENDED TO PROTECT MICROCONTROLLER IF PINS ARE
SHORTED TO GND OR 3.3V AND TO PREVENT RINGING.

THE 1-WIRE BUS CAN EITHER BE IMPLEMENTED IN FIRMWARE
USING TIM1_CH4 ON PA3 OR USART2 TX/RX ON PA2/PA3.

RESISTORS IN SERIES WITH THE JUMPERS ARE TO PREVENT
DAMAGE TO MICROCONTROLLER IF BOTH JUMPERS ARE BRIDGED
AT ONCE. ONLY ONE JUMPER IS MEANT TO BE BRIDGED AT A TIME.

RC ON ENABLE SERVES TWO PURPOSES:

1. EXTEND LOAD SWITCH OUTPUT DISCHARGE TIME. ACTIVE DISCHARGE
2. PREVENT DAMAGING RINGING DUE TO LARGE INPUT CAPACITANCE

DATA SIGNAL (USB AND GPIO) ENABLE SEQUENCE:
1. ENABLE LINE ASSERTED VIA MICROCONTROLLER OR SOLDER BRIDGE
2. LOAD SWITCH ENERGIZES OUTPUT AFTER PROGRAMMED DELAY
3. POWER-ON RESET ADDS FURTHER DELAY, THEN ENABLES DATA SWITCHES
DATA SWITCHES ARE DISABLED IMMEDIATELY IF ANY OF THE FOLLOWING ARE TRUE:
1. ENABLE LINE IS DE-ASSERTED
2. LOAD SWITCH POWER GOOD IS DE-ASSERTED
3. 3.3V RAIL FALLS BELOW POWER-ON RESET THRESHOLD

1 SWDIO 2 ~{RESET}3 SWCLK 4 GND

PINS PC14, PC15, AND PB7 ARE
RESERVED AS HARDWARE REVISION
DETECTION PINS. THE FIRMWARE
WILL USE THESE TO ENSURE THE
CORRECT MICROCONTROLLER PIN
ASSIGNMENTS.


DELAY AFTER DATA_ENABLE ASSERT IS 100MS MINIMUM, 200MS MAXIMUM, 160MS
TYPICAL. ~{RESET}WILL ASSERT IMMEDIATELY IF DATA_ENABLE FALLS BELOW
THRESHOLD.

~{RESET}IS CONSIDERED TO HAVE LOW DRIVE STRENGTH SO IT IS EFFECTIVELY
BUFFERED FOR GPIO SWITCH BY PASSING THROUGH INVERTER TWICE.

THIS DOCUMENT IS SUBJECT TO THE RESTRICTIONS ON SHEET 1 OF THIS DOCUMENT. GND

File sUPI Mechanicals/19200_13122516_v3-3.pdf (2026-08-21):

SIZE; DAI; SCALE; UNIT WT.; DRAWN; DATE(YEAR-MO-DA); CHECKER; ENGINEER; QUALITY; DRAWING APPROVAL; MATL ENGR; MODELED; DESIGN APPROVAL; CONTRACT; NUMBER; CONTRACTOR; SHEET; DRAWING SIZE D; PLACE; DECIMALS; FORMAT: D_TACOM_ENG_1_0; DWG NO.; REVISIONS; DRAWING; REV; DESCRIPTION; APPROVED; (REQUIRED) YEAR-MM-DD; YEAR-MM-DD; US ARMY; COMBAT; CAPABILITIES; DEVELOPMENT COMMAND; ARMAMENTS CENTER; PICATINNY ARSENAL,; NEW JERSEY 07806-5000; (REQUIRED); APPLICATION; NEXT ASSY; USED ON; PMIC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

NOTES:
1. INTERPRET DIMENSIONS AND TOLERANCES IN ACCORDANCE WITH ANSI/ASME Y14.5M-2009.
2. MANUFACTURING PROCESS: ADDITIVE MANUFACTURING - POLYMER POWDER BED FUSION.
ACCEPTABLE TECHNOLOGIES:MULTI-JET FUSION, SELECTIVE LASER SINTERING, OR SELECTIVE ASORBTION FUSION
3. MATERIAL: POLYAMIDE 12 (PA12), OR POLYAMIDE 6 (PA6)
4. FINISH: REMOVE ALL UNSINTERED POWDER. MEDIA BLAST TO UNIFORM FINISH. OPTIONAL BLACK DYE.
5. DESIGN MODEL 100051265 IS REQUIRED TO COMPLETE THE PRODUCT DEFINITION.
6. UNLESS OTHERWISE SPECIFIED, ALL UNTOLERANCED FEATURES SHALL HAVE A PROFILE
TOLERANCE OF
7. OBTAIN DIMENSIONS FOR ALL UNDIMENSIONED FEATURES FROM THE MODEL. ALL VALUES QUERIED
OR DERIVED FROM THE MODEL SHALL BE BASIC
8. PACKAGE PART IN ACCORDANCE WITH MIL-STD-2073-1, METHOD 10, AND TAG PACKAGE WITH THE
FOLLOWING: -100051265-001-1, IAW MIL-STD-130.

ISOMETRIC VIEW
SCALE 2.000
FOR REFERENCE ONLY

THIS DRAWING WAS GENERATED FROM A SOLID MODEL
INCORPORATED BY THE DESIGN ACTIVITY.
PART NO. 13122516

DISTRIBUTION STATEMENT A. APPROVED FOR PUBLIC RELEASE; DISTRIBUTION IS UNLIMITED.

DO NOT SCALE DRAWING
UNLESS OTHERWISE SPECIFIED
TOLERANCES ON ANGLES

DESIGN ACTIVITY
SMALL BUTTON COVER

(REQUIRED) | YEAR-MM-DD
(REQUIRED) | (REQUIRED)

YP
TS
EL2
RA
